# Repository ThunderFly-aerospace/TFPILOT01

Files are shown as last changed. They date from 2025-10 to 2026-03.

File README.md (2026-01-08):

# Teensy 4.1 - Based Flight-Controller for dRehmFlight

This project is a hardware controller board designed specifically for use with the [dRehmFlight open-source flight controller firmware](https://github.com/nickrehm/dRehmFlight). It is based on the Teensy 4.1 microcontroller and provides all the essential interfaces and components needed for a compact, capable flight control unit.

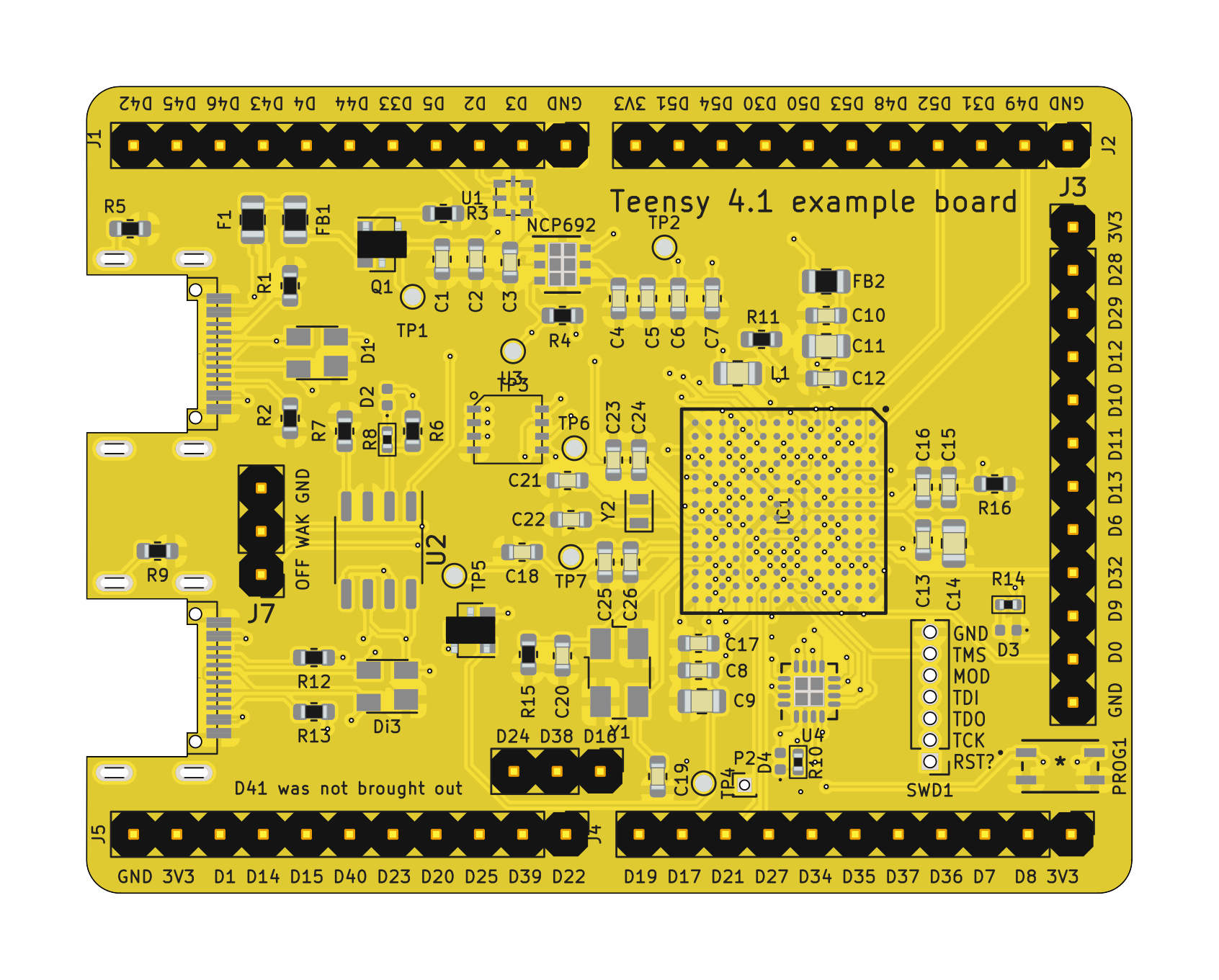
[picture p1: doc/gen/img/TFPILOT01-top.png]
TFPILOT01 top

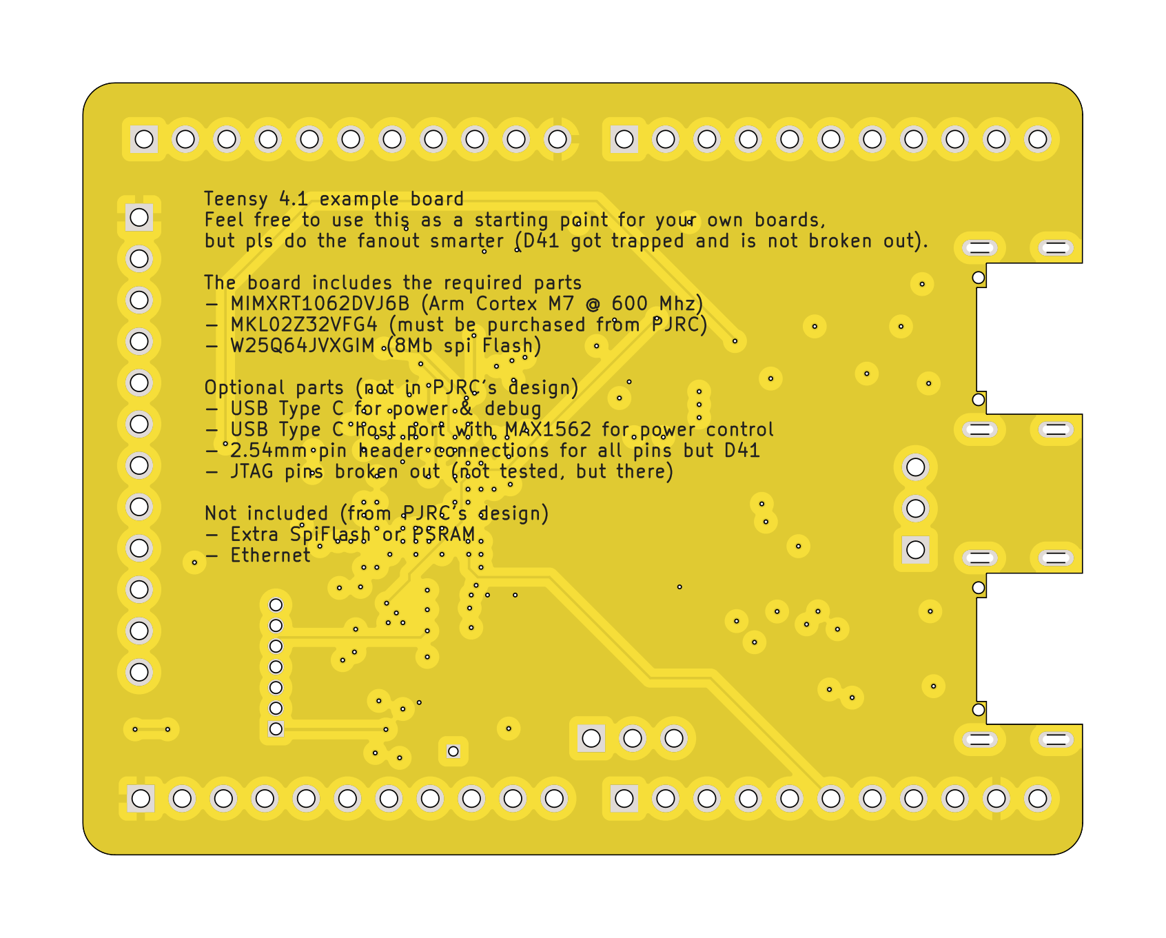
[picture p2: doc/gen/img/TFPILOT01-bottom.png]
TFPILOT01 bottom


## Features

### Core Components

* **Teensy 4.1** (MIMXRT1062DVJ6B – Arm Cortex-M7 @ 600 MHz)
* **MKL02Z32VFG4** bootloader MCU (required for Teensy compatibility)
* **W25Q64JVXGIM** 8 Mb SPI Flash memory

### Sensors

* **GY-91 (MPU9250 + BMP280)** IMU module connected via **SPI** for reduced latency.

  * Replaces the GY-521 module (MPU6050) commonly used in the default dRehmFlight configuration
  * Integrated magnetometer (AK8963) provides full 9‑DOF capability
  * Integrated BMP280 barometric sensor for altitude estimation

### Storage

* **microSD card slot** for onboard data logging

### Power and Connectivity

* **XT30 power connector** for powering both the autopilot and connected servos
* **PWM outputs** using standard RC servo connectors for direct model integration
* **Multiple high-current GPIO outputs** with transistor drivers for heating control, triggering pyrotechnic or other one-shot actuators
* **USB‑C connector** for power and debug interface (compatible with PJRC Teensy bootloader)

### Expansion and Debugging

* **2.54 mm pin header** for access to I/O pins (except D41)
* **JTAG pins** broken out (not yet tested)

## Acknowledgements

This updated board builds upon the original Teensy 4.1 KiCad example design, transforming it into a purpose-built flight controller platform optimized for dRehmFlight. It adds robust sensing, storage, power distribution, and actuator control features for experimental UAV and aerospace applications.

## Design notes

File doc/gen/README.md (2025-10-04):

# PCB

Board size: 61.5x47.5 mm (2.42x1.87 inches)

- This is the size of the rectangle that contains the board
- Thickness: 4.69 mm (185 mils)
- Material: FR4
- Finish: None
- Layers: 4
- Copper thickness: 35 µm

Solder mask: TOP / BOTTOM

- Color: Green

Silk screen: TOP / BOTTOM

- Color: White

Stackup:

| Name | Type | Color | Thickness [µm]| Material | Er | Loss tan |
|---|---|---|---|---|---|---|
| F.SilkS | Top Silk Screen | | | | | |
| F.Paste | Top Solder Paste | | | | | |
| F.Mask | Top Solder Mask | Green | 10 | | | |
| F.Cu | copper | | 35 | | | |
| dielectric 1 | core | | 1510 | FR4 | 4.5 | 0.020 |
| In1.Cu | copper | | 35 | | | |
| dielectric 2 | prepreg | | 1510 | FR4 | 4.5 | 0.020 |
| In2.Cu | copper | | 35 | | | |
| dielectric 3 | core | | 1510 | FR4 | 4.5 | 0.020 |
| B.Cu | copper | | 35 | | | |
| B.Mask | Bottom Solder Mask | Green | 10 | | | |
| B.Paste | Bottom Solder Paste  | | | | | |
| B.SilkS | Bottom Silk Screen | | | | | |

# Important sizes

Clearance: 0.1 mm (4 mils)

Track width: 0.15 mm (6 mils)

- By design rules: 0.15 mm (6 mils)

Drill: 0.25 mm (10 mils)

- Vias: 0.25 mm (10 mils) [Design: 0.25 mm (10 mils)]
- Pads: 0.6 mm (24 mils)
- The above values are real drill sizes, they add 0.1 mm (4 mils) to plated holes (PTH)

Via: 0.45/0.15 mm (18/6 mils)

- By design rules: 0.15/0.15 mm (6/6 mils)
- Micro via: yes [0.2/0.1 mm (8/4 mils)]
- Buried/blind via: yes
- Total: 145 (thru: 145 buried/blind: 0 micro: 0)

Outer Annular Ring: 0.1 mm (4 mils)

- By design rules: 0.13 mm (5 mils)

Eurocircuits class: 8E
- Using min drill 0.2 mm for an OAR of 0.13 mm

# General stats

Components count: (SMD/THT)

- Top: 62/11 (SMD + THT)
- Bottom: 0/0 (NONE)

Defined tracks:

- 0.16 mm (6 mils)
- 0.2 mm (8 mils)

Used tracks:

- 0.15 mm (6 mils) (68) defined: no
- 0.16 mm (6 mils) (744) defined: yes
- 0.2 mm (8 mils) (173) defined: yes
- 0.25 mm (10 mils) (30) defined: no

Defined vias:

- 0.5/0.15 mm (20/6 mils)

Used vias:

- 0.45/0.15 mm (18/6 mils) (Count: 145, Aspect: 10.4 C) defined: no

Holes (excluding vias):

- 0.5 mm (20 mils) (1)
- 0.65 mm (26 mils) (11)
- 1.0 mm (39 mils) (62)

Oval holes:

- 0.5x1.65 mm (20x65 mils) (8)

Drill tools (including vias and computing adjusts and rounding):

- 0.25 mm (10 mils) (145)
- 0.6 mm (24 mils) (9)
- 0.65 mm (26 mils) (4)
- 0.75 mm (30 mils) (7)
- 1.1 mm (43 mils) (62)

Solder paste stats:

Using a paste with 87.75 % alloy, that has an specific gravity for the alloy of 7.4 g/cm³
and 1.0 g/cm³ for the flux. This paste has an specific gravity of  4.15 g/cm³.

The stencil thickness is  0.12 mm.

| Side | Pads with paste | Area [mm²] | Paste [g] |
|---|---|---|---|
| Total  | 406 | 166.59 | 0.83 |

Note: this is just an approximation to the theoretical value. Margins of the solder mask and waste aren't computed.

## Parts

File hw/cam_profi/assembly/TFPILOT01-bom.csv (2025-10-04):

Component | Description | Part | References | Value | Footprint | Quantity Per PCB | Datasheet | mfgr | mpn | height | mouser part number | mouser price/stock | manufacturer_name | manufacturer_part_number
1 | Unpolarized capacitor | C | C21C22 | 9pf | C_0603_1608Metric | 2 | ~ | Jellybean (X7R or better) | GRM1885C1H9R0DA01D
2 | Unpolarized capacitor | C | C19C20 | 10pf | C_0603_1608Metric | 2 | ~ | Jellybean (X7R or better) | CC0603KRNPO9BN100
3 | Unpolarized capacitor | C | C5C16 | 10nf | C_0603_1608Metric | 2 | ~ | Jellybean (X7R or better) | 0603B103K160CT
4 | Unpolarized capacitor | C | C1C2C4C8C10C13C17C18C23C25 | 0.22uf | C_0603_1608Metric | 10 | ~ | Jellybean (X7R or better) | CC0603KRX7R6BB224
5 | Unpolarized capacitor | C | C3C7 | 2.2uf | C_0603_1608Metric | 2 | ~ | Jellybean (X7R or better) | CL10B225KP8NNNC
6 | Unpolarized capacitor | C | C6C12C15C24C26 | 4.7uf | C_0603_1608Metric | 5 | ~ | Jellybean (X7R or better) | CL10B475KQ8NQNC
7 | Unpolarized capacitor | C | C9C11C14 | 10uf | C_0805_2012Metric | 3 | ~ | Jellybean (X7R or better) | GRM21BR71A106KA73K
8 | dual schottky barrier diode, common cathode | BAT54C | D5 | BAT54C | SOT-23 | 1 | http://www.diodes.com/_files/datasheets/ds11005.pdf
9 | Light emitting diode | LED | D3D4 | LED | LED_0402_1005Metric | 2 | ~
10 | TVS Diode Array, 5.5V Standoff, 3 Channels, SOT-143 package | SP0503BAHT | D1 | SP0503BAHT | SOT-143 | 1 | http://www.littelfuse.com/~/media/files/littelfuse/technical%20resources/documents/data%20sheets/sp05xxba.pdf
11 | Fuse | Fuse | F1 | Fuse | R_0805_2012Metric | 1 | ~ | Bel Fuse Inc | 0ZCK0050FF2E
12 | Ferrite bead | Ferrite_Bead | FB1FB2 | Ferrite_Bead | R_0805_2012Metric | 2 | ~ | Taiyo Yuden | FBMH2012HM121-T‎
13 | IC MCU 32BIT EXT MEM 196MAPBGA | MIMXRT1062DVJ6B | IC1 | MIMXRT1062DVJ6B | BGA196C80P14X14_1200X1200X152 | 1 | https://www.nxp.com/docs/en/nxp/data-sheets/IMXRT1060CEC.pdf |  |  | 1.52 | 771-MIMXRT1062DVJ6B | https://www.mouser.co.uk/ProductDetail/NXP-Semiconductors/MIMXRT1062DVJ6B?qs=BJlw7L4Cy7%252B08A9rbTO5WQ%3D%3D | NXP | MIMXRT1062DVJ6B
14 | Generic connector, single row, 01x03, script generated (kicad-library-utils/schlib/autogen/connector/) | Conn_01x03_Male | J6J7 | Conn_01x03_Male | PinHeader_1x03_P2.54mm_Vertical | 2 | ~
15 | Inductor | L | L1 | 4.7uH | C_0805_2012Metric | 1 | ~ |  | LQM21PN4R7MGRD
16 | 3x3mm LDO, 1A | OnSemi NCP692, fixed version | NCP692 | OnSemi NCP692, fixed version | DFN-6-1EP_3x3mm_P0.95mm_EP1.7x2.6mm | 1 | https://www.onsemi.com/pdf/datasheet/ncp690-d.pdf | Onsemi | NCP692MN33T2G
17 | Push button switch, generic, two pins | SW_Push | PROG1 | SW_Push | KMR241GLFS | 1 |  | C&K | KMR241GLFS
18 | P-MOSFET transistor, gate/drain/source | Q_PMOS_GDS | Q1 | Q_PMOS_GDS_DMP3125L | SOT-23 | 1 | https://www.diodes.com/assets/Datasheets/DMP3125L.pdf
19 | Resistor | R | R10R14 | 1k | R_0402_1005Metric | 2 | ~
20 | Resistor | R | R1R2 | 5.1k | R_0603_1608Metric | 2 | ~ | Jellybean | RC0603FR-075K1L
21 | Resistor | R | R3R4R11 | 100k | R_0603_1608Metric | 3 | ~
22 | Resistor | R | R5 | 1M | R_0603_1608Metric | 1 | ~
23 | Resistor | R | R15 | 2.2M | R_0603_1608Metric | 1 | ~
24 | Generic connector, single row, 01x07, script generated (kicad-library-utils/schlib/autogen/connector/) | Conn_01x07_Female | SWD1 | SWD | PinHeader_1x07_P1.27mm_Vertical | 1 | ~
25 | Kinetis KL02 series, 48-MHz/32-bit ARM Cortex-M0+, 32 kB flash, 4 kB SRAM, QFN-16 | MKL02Z32VFG4 | U4 | MKL02Z32VFG4 | QFN-16-1EP_3x3mm_P0.5mm_EP1.8x1.8mm | 1 | http://www.nxp.com/docs/en/data-sheet/KL02P32M48SF0.pdf | Supplied by Roest Coffee | Custom firmware part
26 | Flash chip for T4.1 designs, XSON-8 package, W25Q64JVXGIM TR, NOR Flash spiFlash, 64M-bit, DTR, 4Kb Uniform Sector | W25Q64VXGIM | U3 | W25Q64JVXGIM | XSON8_4x4mm | 1 | https://www.winbond.com/resource-files/W25Q64JV%20RevK%2003102021%20Plus.pdf
27 |  | opto_APA102-2020 | U1 | opto_APA102-2020 | APA102-2020 | 1 | https://www.digikey.com/htmldatasheets/production/2046355/0/0/1/3587.pdf
28 | USB 2.0-only Type-C Receptacle connector | USB_C_Receptacle_USB2.0 | USB_UFP1 | USB_C_Receptacle_USB2.0 | TYPE-C-31-M-14 | 1 | https://www.usb.org/sites/default/files/documents/usb_type-c.zip
29 | Two pin crystal | Crystal | Y2 | Crystal | Crystal_SMD_2012-2Pin_2.0x1.2mm | 1 | ~ | Abracon | ABS06-32.768KHZ-9-1-T
30 | Four pin crystal, GND on pins 2 and 4 | Crystal_GND24 | Y1 | Crystal_GND23 | Crystal_SMD_Abracon_ABM3B-4Pin_5.0x3.2mm | 1 | ~

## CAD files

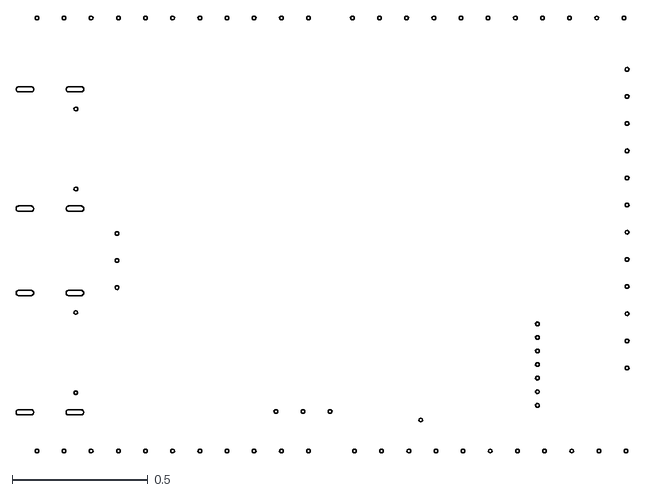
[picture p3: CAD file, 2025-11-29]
doc/gen/dxf/TFPILOT01-User_9.dxf
2.26 x 1.61

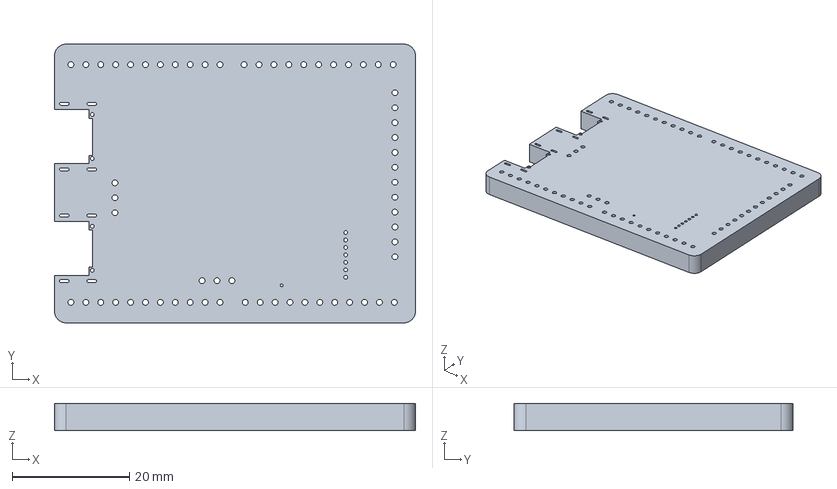
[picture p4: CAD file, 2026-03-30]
doc/gen/TFPILOT01.step
61.5 x 47.5 x 4.60 mm

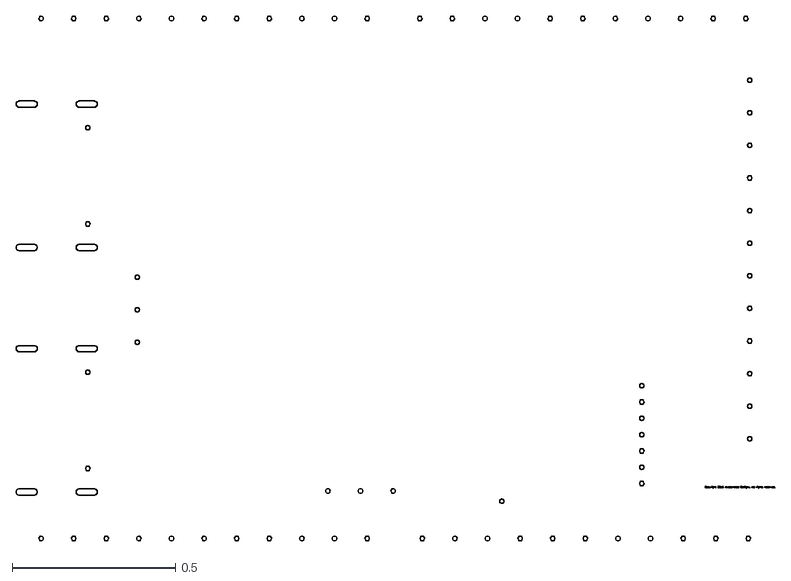
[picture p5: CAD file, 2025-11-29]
doc/gen/dxf/TFPILOT01-User_Comments.dxf
2.33 x 1.61

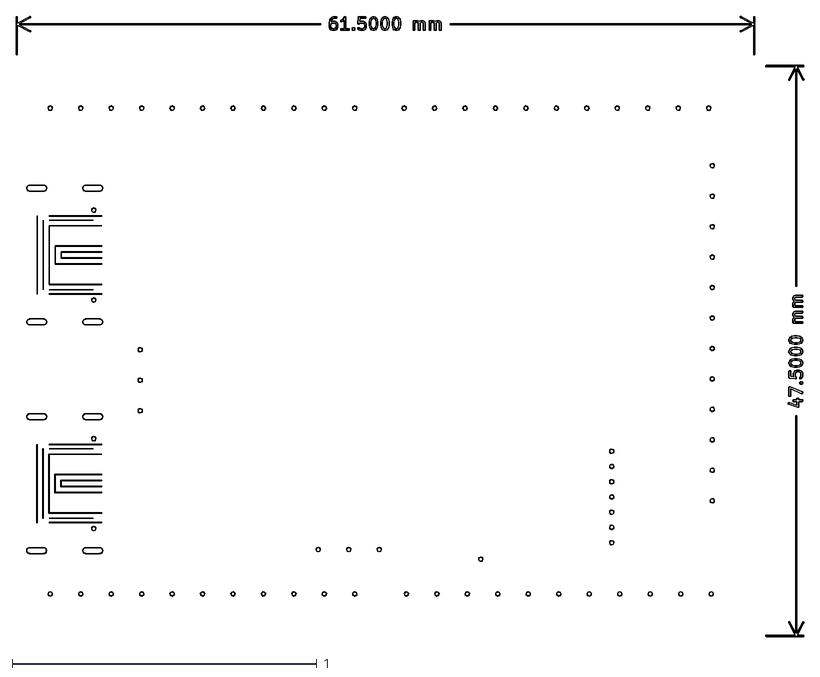
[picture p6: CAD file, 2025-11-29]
doc/gen/dxf/TFPILOT01-User_Drawings.dxf
2.59 x 2.03

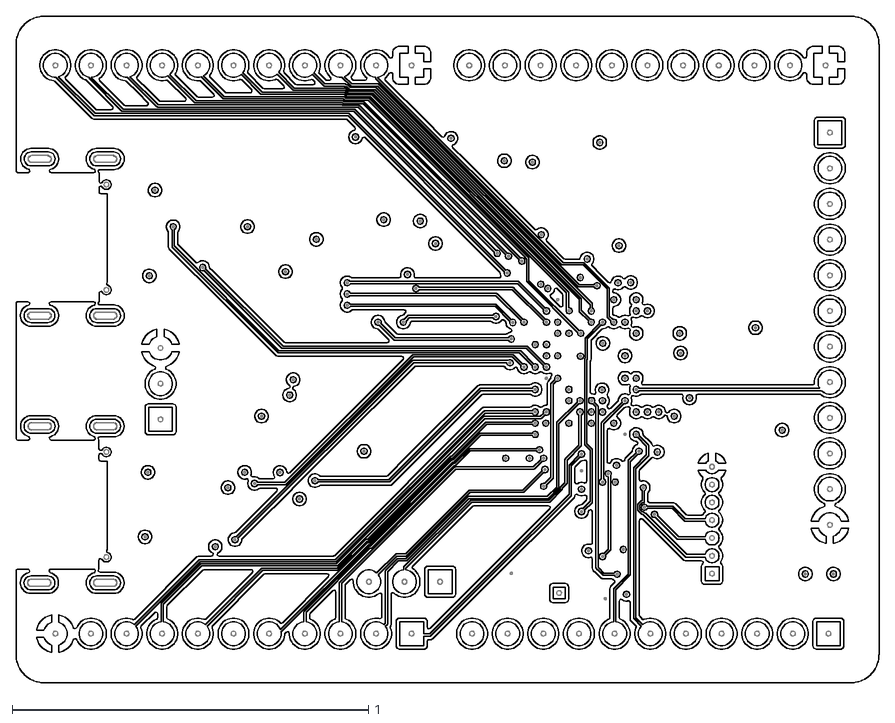
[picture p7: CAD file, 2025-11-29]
doc/gen/dxf/TFPILOT01-In2_Cu.dxf
2.42 x 1.87

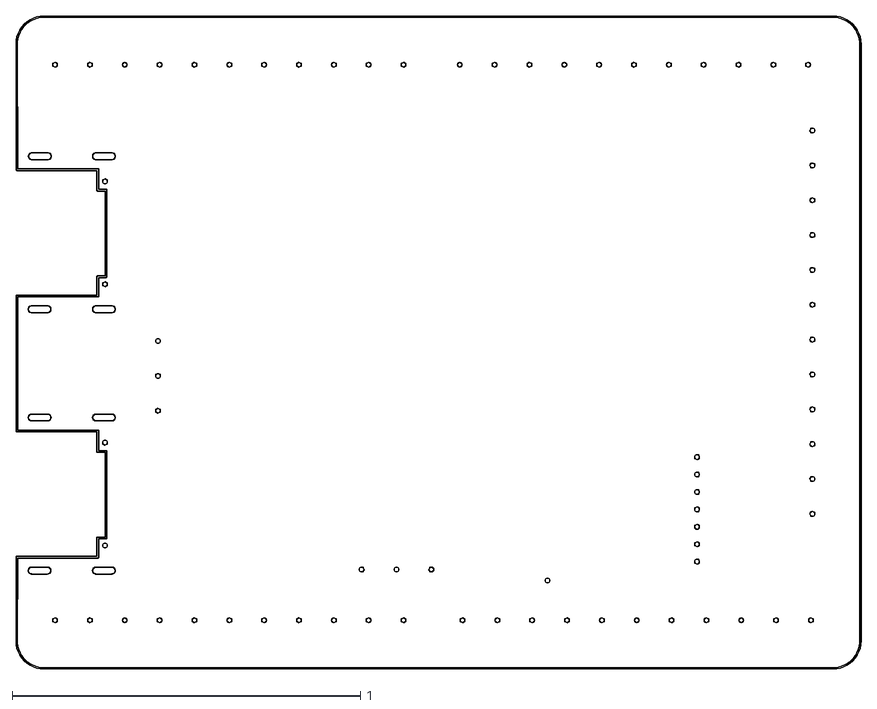
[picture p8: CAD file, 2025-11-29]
doc/gen/dxf/TFPILOT01-Edge_Cuts.dxf
2.43 x 1.87

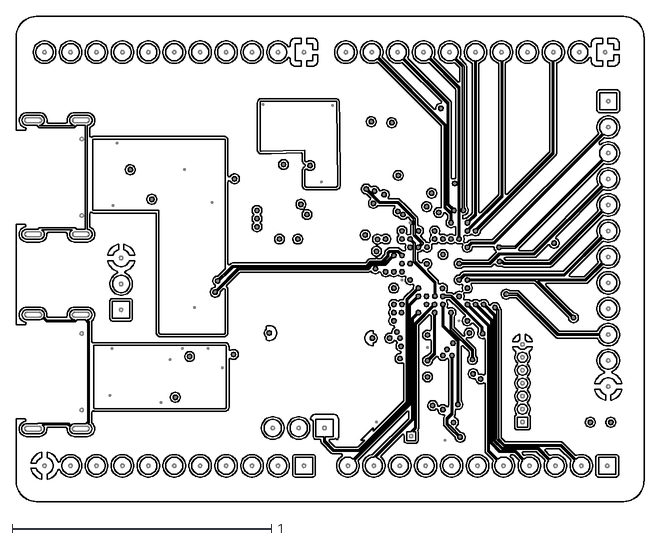
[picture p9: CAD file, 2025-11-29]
doc/gen/dxf/TFPILOT01-In1_Cu.dxf
2.42 x 1.87

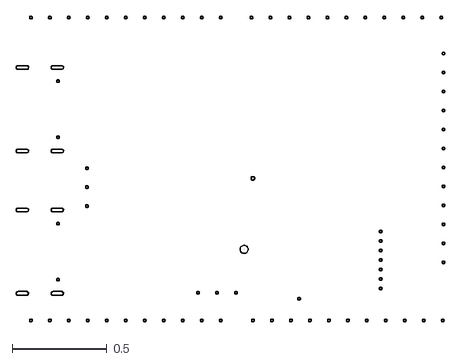
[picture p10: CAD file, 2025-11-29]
doc/gen/dxf/TFPILOT01-F_Adhesive.dxf
2.26 x 1.61

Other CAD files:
doc/gen/dxf/TFPILOT01-B_Adhesive.dxf
doc/gen/dxf/TFPILOT01-B_Cu.dxf
doc/gen/dxf/TFPILOT01-B_Mask.dxf
doc/gen/dxf/TFPILOT01-B_Paste.dxf
doc/gen/dxf/TFPILOT01-B_Silkscreen.dxf
doc/gen/dxf/TFPILOT01-F_Courtyard.dxf
doc/gen/dxf/TFPILOT01-F_Cu.dxf
doc/gen/dxf/TFPILOT01-F_Fab.dxf
doc/gen/dxf/TFPILOT01-F_Mask.dxf
doc/gen/dxf/TFPILOT01-F_Paste.dxf
doc/gen/dxf/TFPILOT01-F_Silkscreen.dxf

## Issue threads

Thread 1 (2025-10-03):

IMU integration

kaklik, 2025-10-03:
Lepší je použít GY-91 s MPU9250, který má i magnetometr. Je jej spíše vhodné připojit přes SPI, místo defaultního I2C v [dRehmFlight](https://github.com/nickrehm/dRehmFlight).

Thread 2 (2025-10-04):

Check existing design for defects

kaklik, 2025-10-04:
- [lots of important information there](https://www.pjrc.com/store/ic_mkl02_t4.html)
-

## Know bugs (from the original readme)
This version is tested and works, but the MAX1562 that I used for the USB switch has inverted polarity from what is expected. You can get around this by using the alternate part MAX1563, or something else. Only reason I went with this 4A chip is the parts shortage.

I just removed the chip and soldered bodge-wires to bypass it. This also works, but I guess it then lacks protection. I've tested with keyboard & mouse.

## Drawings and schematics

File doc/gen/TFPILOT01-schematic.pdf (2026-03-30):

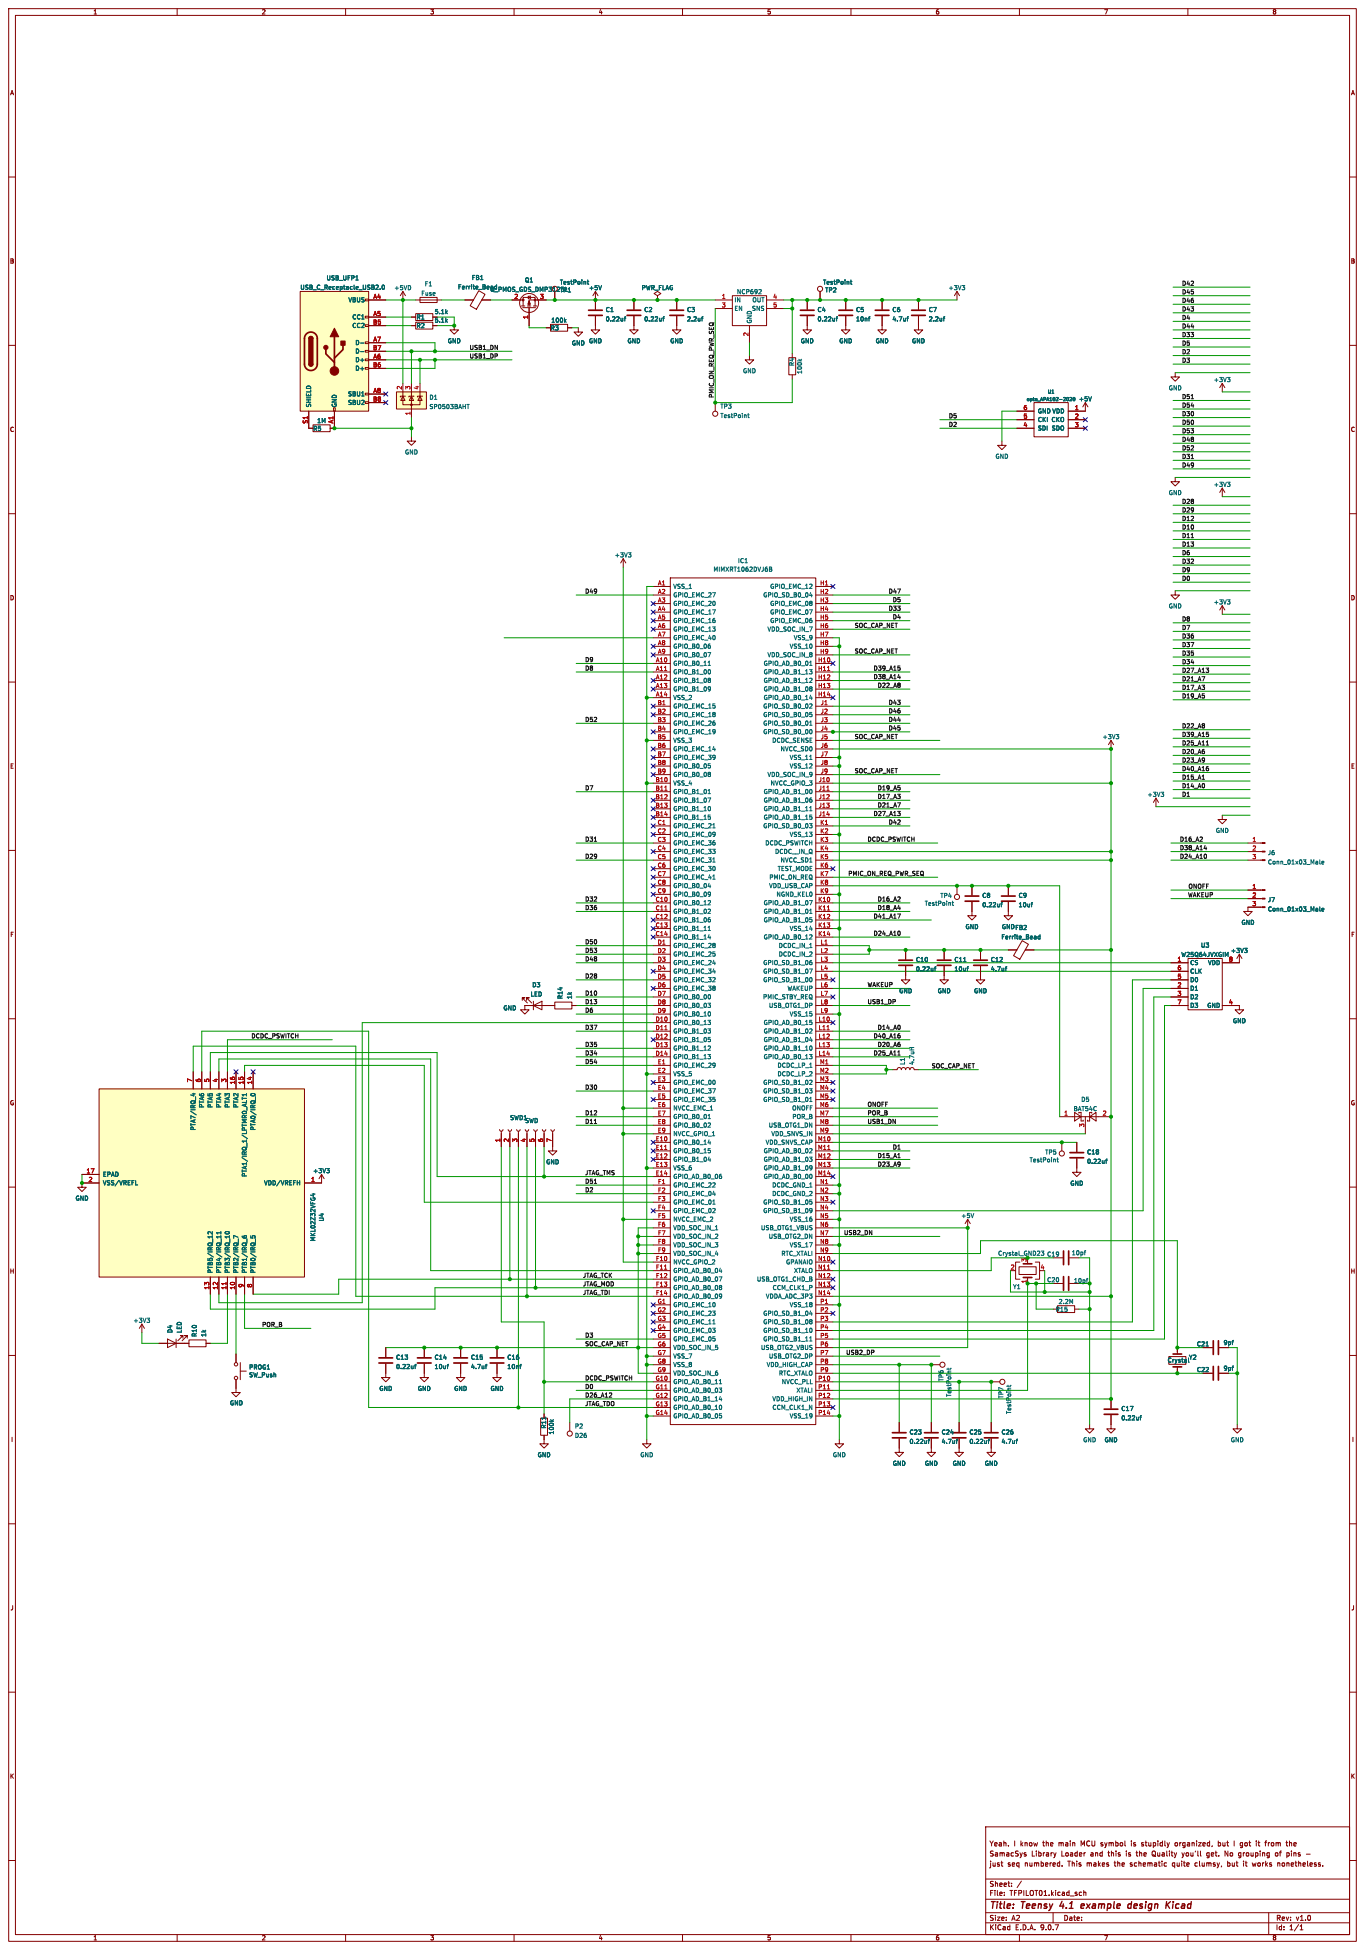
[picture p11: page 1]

2 OUT 4 SNS 5 NCP692 GND GND L14.7uH

7 EPAD 17 VDD/VREFH 1 VSS/VREFL 2 PTB0/IRQ_5

File: TFPILOT01.kicad_sch Sheet: /
Id: 1/1 Title: Teensy 4.1 example design Kicad

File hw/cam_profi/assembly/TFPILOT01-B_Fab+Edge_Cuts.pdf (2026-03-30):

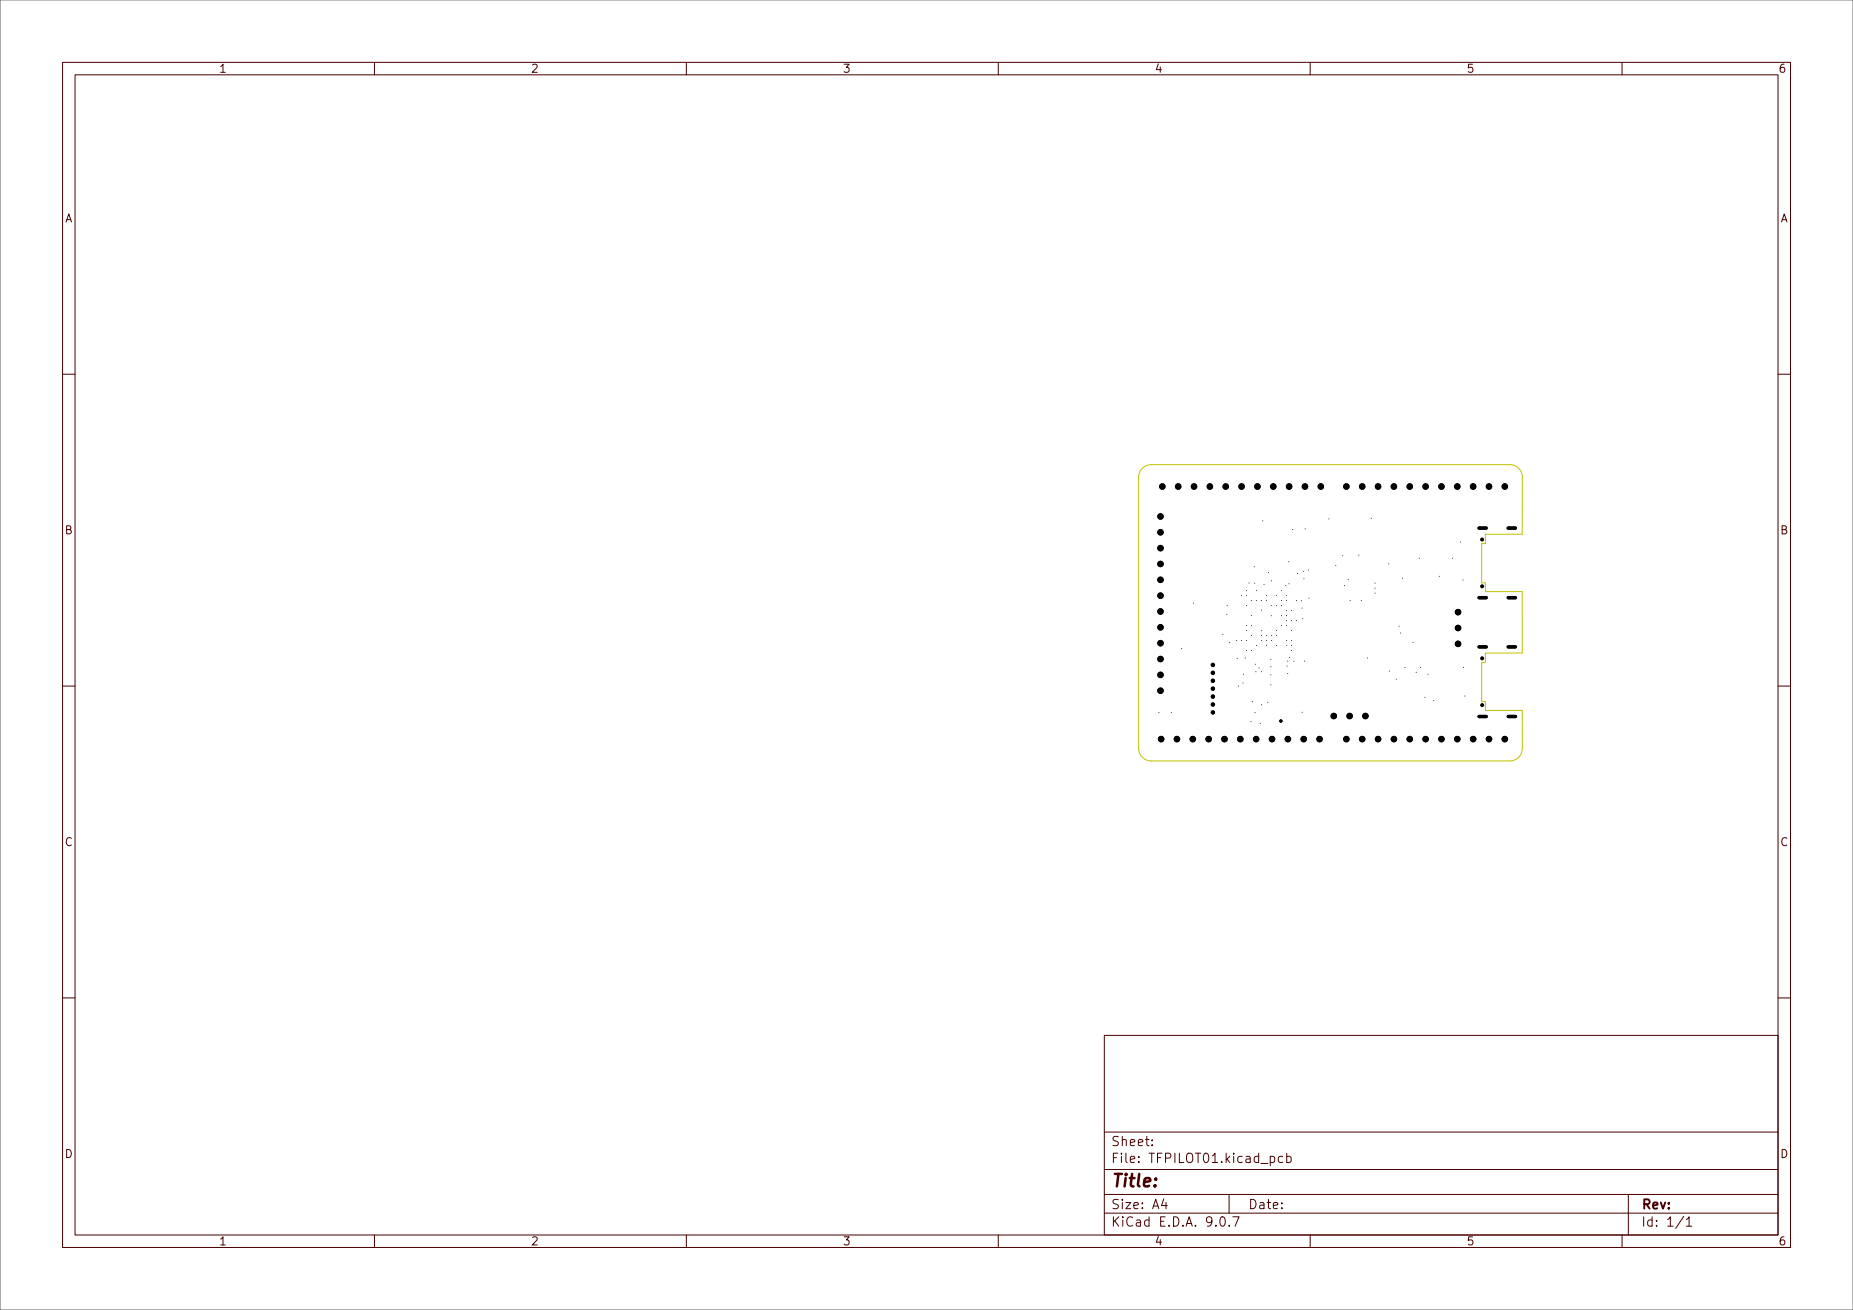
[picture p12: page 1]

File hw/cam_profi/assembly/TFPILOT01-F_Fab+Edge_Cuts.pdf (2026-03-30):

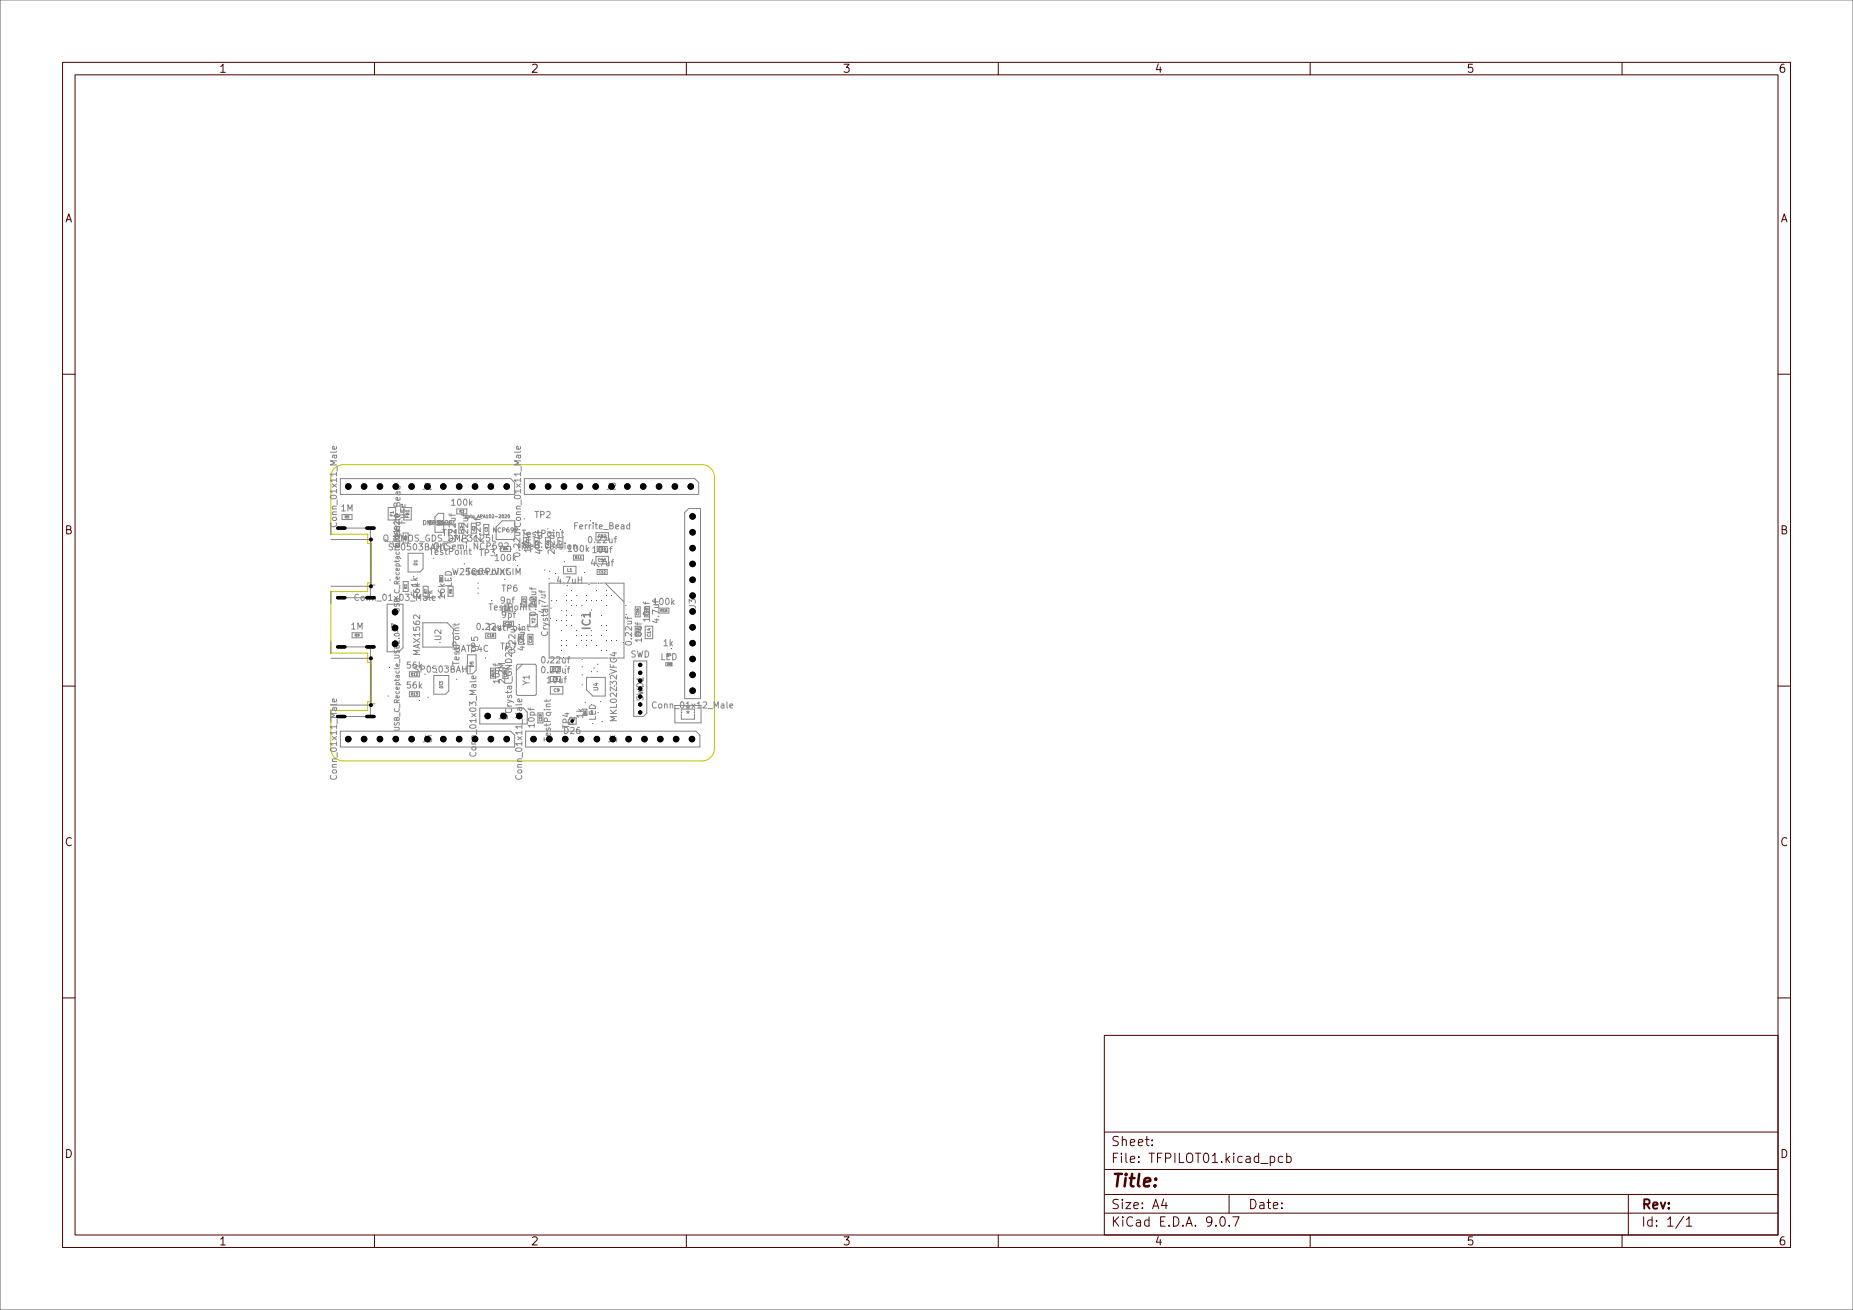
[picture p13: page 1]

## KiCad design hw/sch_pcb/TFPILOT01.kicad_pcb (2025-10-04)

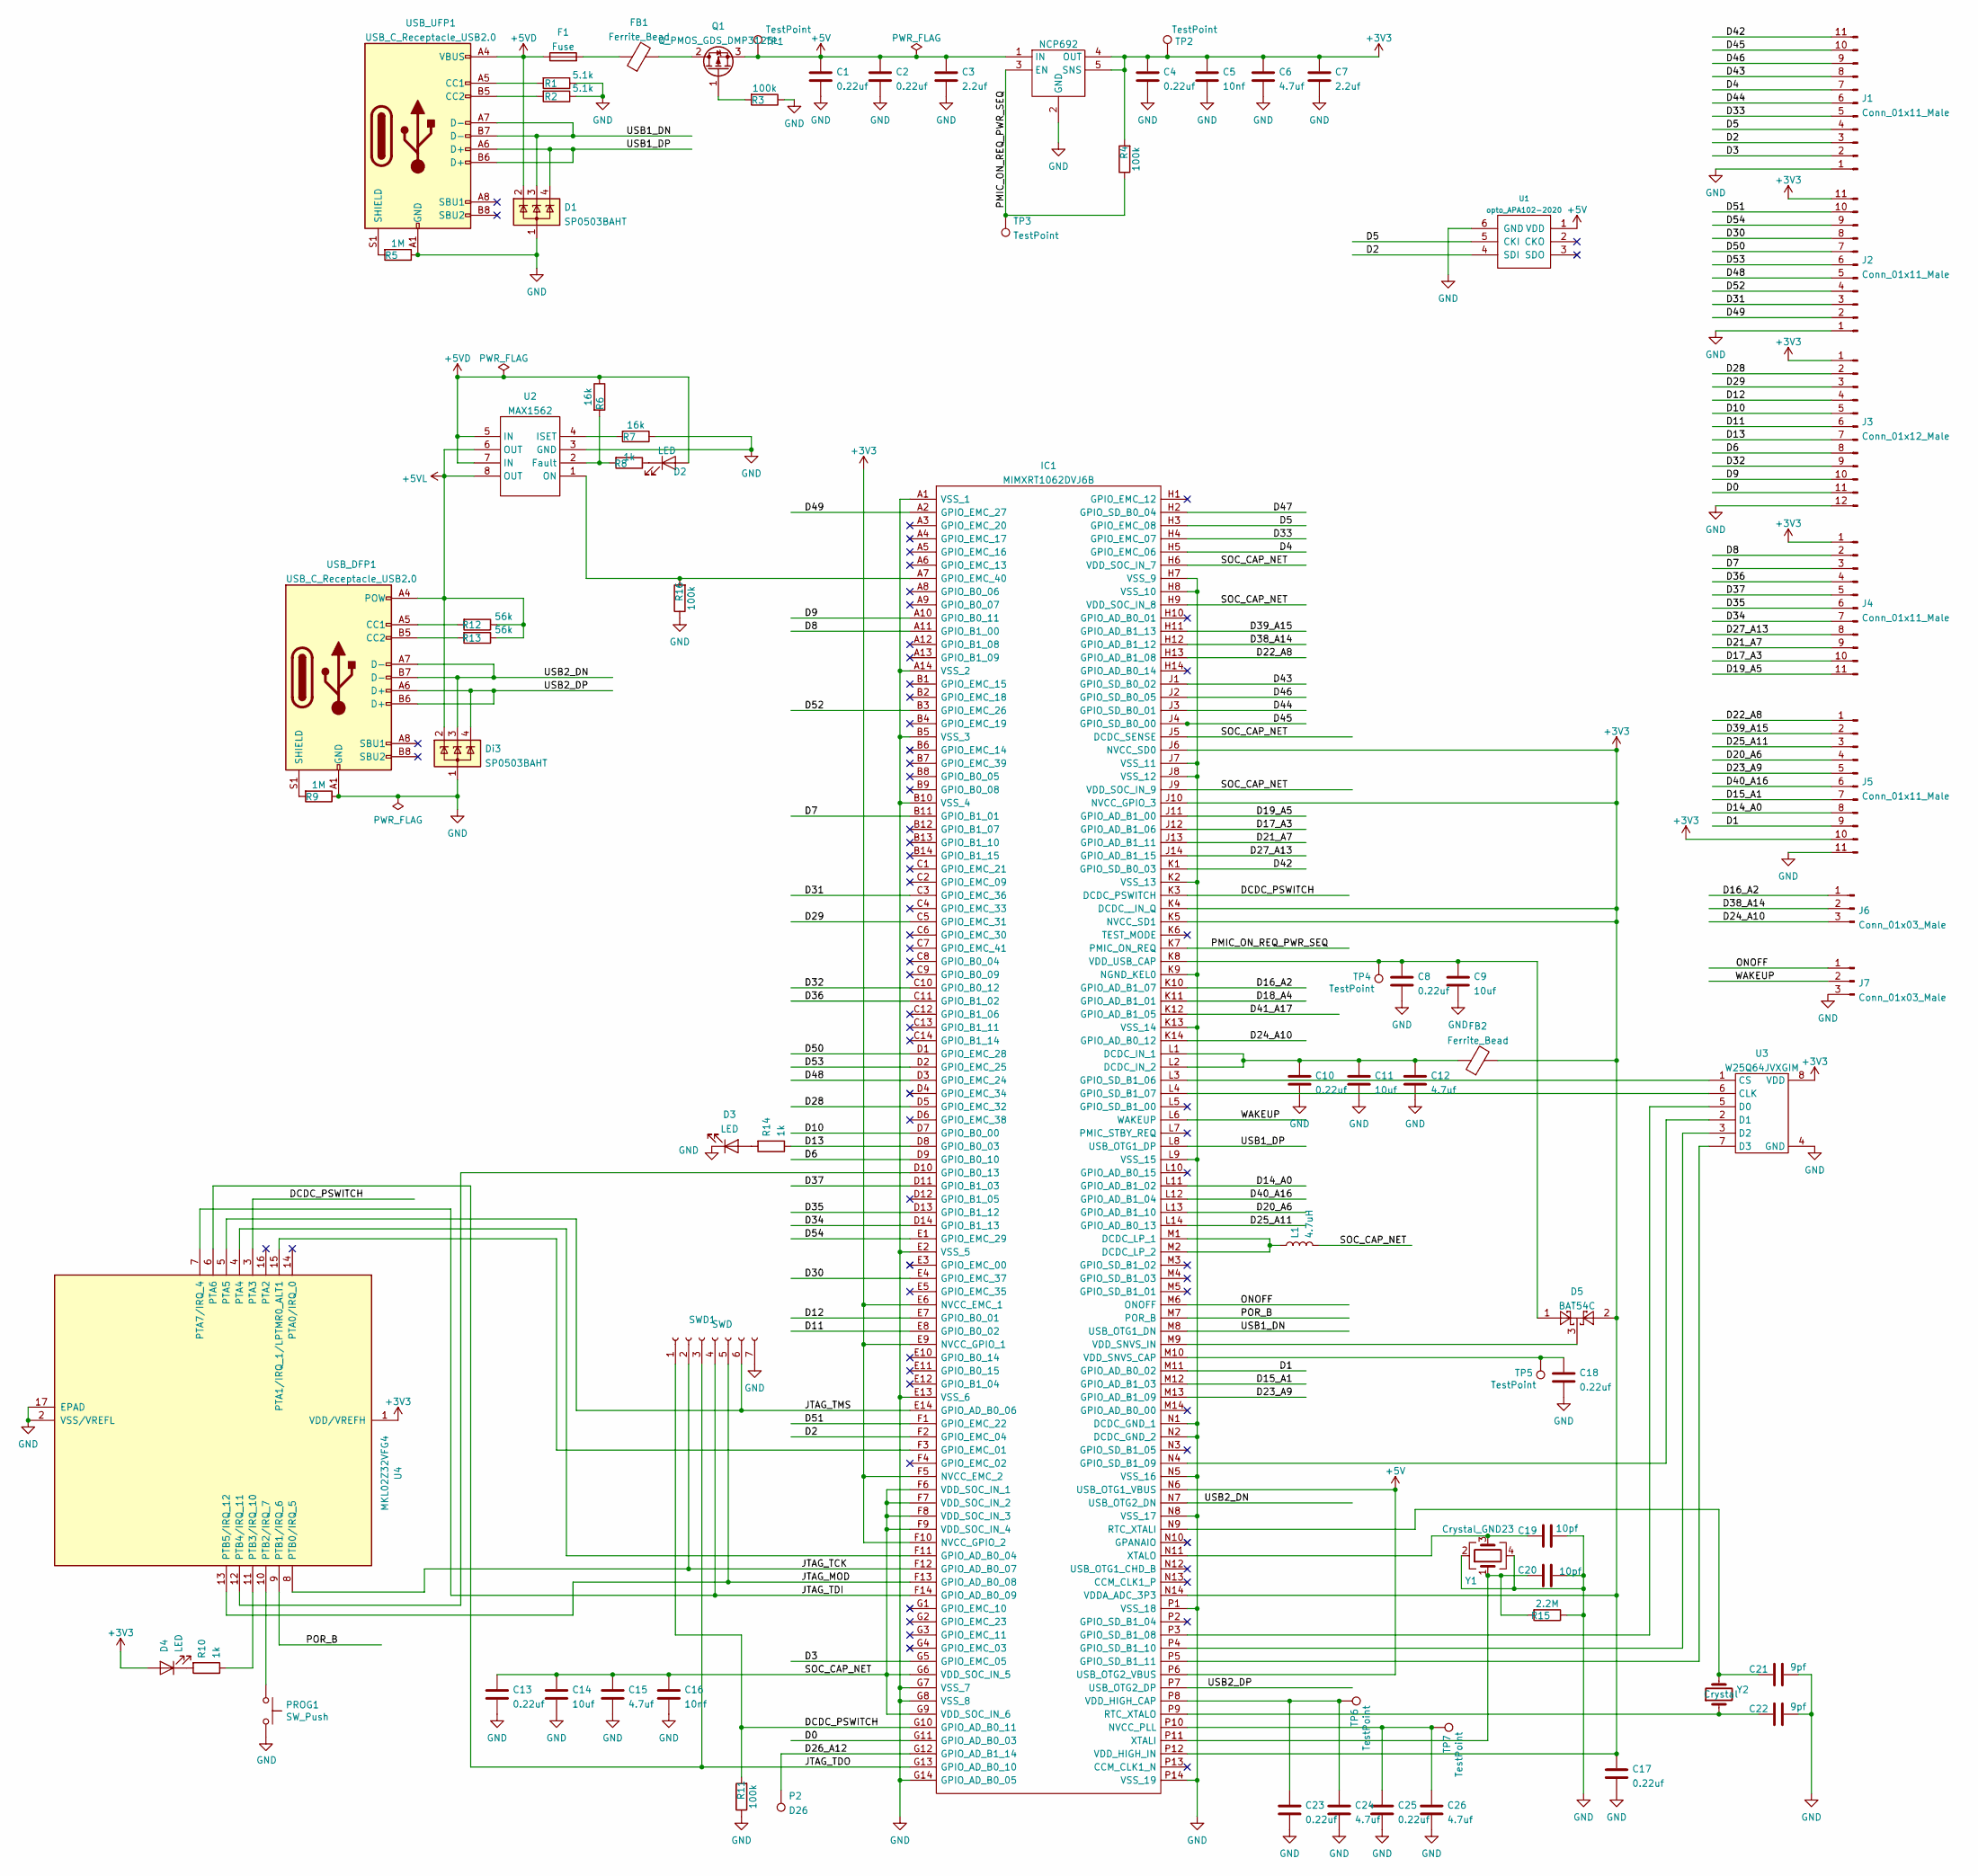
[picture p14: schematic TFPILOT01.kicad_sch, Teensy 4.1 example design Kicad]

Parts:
C1, C2, C4, C8, C10, C13, C17, C18, C23, C25: 0.22uf; C_0603_1608Metric; MPN CC0603KRX7R6BB224
C3, C7: 2.2uf; C_0603_1608Metric; MPN CL10B225KP8NNNC
C5, C16: 10nf; C_0603_1608Metric; MPN 0603B103K160CT
C6, C12, C15, C24, C26: 4.7uf; C_0603_1608Metric; MPN CL10B475KQ8NQNC
C9, C11, C14: 10uf; C_0805_2012Metric; MPN GRM21BR71A106KA73K
C19, C20: 10pf; C_0603_1608Metric; MPN CC0603KRNPO9BN100
C21, C22: 9pf; C_0603_1608Metric; MPN GRM1885C1H9R0DA01D
D1: SP0503BAHT; SOT-143
D2, D3, D4: LED; LED_0402_1005Metric
D5: BAT54C; SOT-23
Di3: SP0503BAHT; SOT-143
F1: Fuse; R_0805_2012Metric; MPN 0ZCK0050FF2E
FB1, FB2: Ferrite_Bead; R_0805_2012Metric; MPN FBMH2012HM121-T‎
IC1: MIMXRT1062DVJ6B; BGA196C80P14X14_1200X1200X152; Mouser Part Number 771-MIMXRT1062DVJ6B
J1, J2, J4, J5: Conn_01x11_Male; PinHeader_1x11_P2.54mm_Vertical
J3: Conn_01x12_Male; PinHeader_1x12_P2.54mm_Vertical
J6, J7: Conn_01x03_Male; PinHeader_1x03_P2.54mm_Vertical
L1: 4.7uH; C_0805_2012Metric; MPN LQM21PN4R7MGRD
NCP692: OnSemi NCP692, fixed version; DFN-6-1EP_3x3mm_P0.95mm_EP1.7x2.6mm; MPN NCP692MN33T2G
P2: D26; PinHeader_1x01_P1.00mm_Vertical
PROG1: SW_Push; KMR241GLFS; MPN KMR241GLFS
Q1: Q_PMOS_GDS_DMP3125L; SOT-23
R1, R2: 5.1k; R_0603_1608Metric; MPN RC0603FR-075K1L
R3, R4, R11, R16: 100k; R_0603_1608Metric
R5, R9: 1M; R_0603_1608Metric
R6, R7: 16k; R_0603_1608Metric
R8, R10, R14: 1k; R_0402_1005Metric
R12, R13: 56k; R_0603_1608Metric; MPN RMCF0603FT56K0
R15: 2.2M; R_0603_1608Metric
SWD1: SWD; PinHeader_1x07_P1.27mm_Vertical
TP1, TP2, TP3, TP4, TP5, TP6, TP7: TestPoint; TestPoint_Pad_D1.0mm
U1: opto_APA102-2020; APA102-2020
U2: MAX1562; SO-8_3.9x4.9mm_P1.27mm
U3: W25Q64JVXGIM; XSON8_4x4mm
U4: MKL02Z32VFG4; QFN-16-1EP_3x3mm_P0.5mm_EP1.8x1.8mm; MPN Custom firmware part
USB_DFP1: USB_C_Receptacle_USB2.0; TYPE-C-31-M-14
USB_UFP1: USB_C_Receptacle_USB2.0; TYPE-C-31-M-14
Y1: Crystal_GND23; Crystal_SMD_Abracon_ABM3B-4Pin_5.0x3.2mm
Y2: Crystal; Crystal_SMD_2012-2Pin_2.0x1.2mm; MPN ABS06-32.768KHZ-9-1-T

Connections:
+3V3: C4.1, C5.1, C6.1, C7.1, C17.1, D4.2 (A), D5.2, FB2.2, IC1.E6 (NVCC_EMC_1), IC1.E9 (NVCC_GPIO_1), IC1.F5 (NVCC_EMC_2), IC1.F10 (NVCC_GPIO_2), IC1.J6 (NVCC_SD0), IC1.J10 (NVCC_GPIO_3), IC1.K4 (DCDC__IN_Q), IC1.K5 (NVCC_SD1), IC1.N14 (VDDA_ADC_3P3), IC1.P12 (VDD_HIGH_IN), J2.11, J3.1, J4.1, J5.10, NCP692.4 (OUT), NCP692.5 (SNS), R4.2, TP2.1, U3.8 (VDD), U4.1 (VDD/VREFH)
+5V: C1.1, C2.1, C3.1, IC1.N6 (USB_OTG1_VBUS), IC1.P6 (USB_OTG2_VBUS), NCP692.1 (IN), NCP692.6 (IN), Q1.3 (S), TP1.1, U1.1 (VDD)
+5VD: D1.2 (K), D2.2 (A), F1.1, R6.1, U2.5 (IN), U2.7 (IN), USB_UFP1.A4 (VBUS), USB_UFP1.A9 (VBUS), USB_UFP1.B4 (VBUS), USB_UFP1.B9 (VBUS)
+5VL: Di3.2 (K), R12.1, R13.1, U2.6 (OUT), U2.8 (OUT), USB_DFP1.A4 (POW), USB_DFP1.A9 (POW), USB_DFP1.B4 (POW), USB_DFP1.B9 (POW)
/D0: IC1.G11 (GPIO_AD_B0_03), J3.11
/D1: IC1.M11 (GPIO_AD_B0_02), J5.9
/D2: IC1.F2 (GPIO_EMC_04), J1.3, U1.4 (SDI)
/D3: IC1.G5 (GPIO_EMC_05), J1.2
/D4: IC1.H5 (GPIO_EMC_06), J1.7
/D5: IC1.H3 (GPIO_EMC_08), J1.4, U1.5 (CKI)
/D6: IC1.D9 (GPIO_B0_10), J3.8
/D7: IC1.B11 (GPIO_B1_01), J4.3
/D8: IC1.A11 (GPIO_B1_00), J4.2
/D9: IC1.A10 (GPIO_B0_11), J3.10
/D10: IC1.D7 (GPIO_B0_00), J3.5
/D11: IC1.E8 (GPIO_B0_02), J3.6
/D12: IC1.E7 (GPIO_B0_01), J3.4
/D13: IC1.D8 (GPIO_B0_03), J3.7, R14.1
/D14_A0: IC1.L11 (GPIO_AD_B1_02), J5.8
/D15_A1: IC1.M12 (GPIO_AD_B1_03), J5.7
/D16_A2: IC1.K10 (GPIO_AD_B1_07), J6.1
/D17_A3: IC1.J12 (GPIO_AD_B1_06), J4.10
/D18_A4: IC1.K11 (GPIO_AD_B1_01)
/D19_A5: IC1.J11 (GPIO_AD_B1_00), J4.11
/D20_A6: IC1.L13 (GPIO_AD_B1_10), J5.4
/D21_A7: IC1.J13 (GPIO_AD_B1_11), J4.9
/D22_A8: IC1.H13 (GPIO_AD_B1_08), J5.1
/D23_A9: IC1.M13 (GPIO_AD_B1_09), J5.5
/D24_A10: IC1.K14 (GPIO_AD_B0_12), J6.3
/D25_A11: IC1.L14 (GPIO_AD_B0_13), J5.3
/D26_A12: IC1.G12 (GPIO_AD_B1_14), P2.1
/D27_A13: IC1.J14 (GPIO_AD_B1_15), J4.8
/D28: IC1.D5 (GPIO_EMC_32), J3.2
/D29: IC1.C5 (GPIO_EMC_31), J3.3
/D30: IC1.E4 (GPIO_EMC_37), J2.8
/D31: IC1.C3 (GPIO_EMC_36), J2.3
/D32: IC1.C10 (GPIO_B0_12), J3.9
/D33: IC1.H4 (GPIO_EMC_07), J1.5
/D34: IC1.D14 (GPIO_B1_13), J4.7
/D35: IC1.D13 (GPIO_B1_12), J4.6
/D36: IC1.C11 (GPIO_B1_02), J4.4
/D37: IC1.D11 (GPIO_B1_03), J4.5
/D38_A14: IC1.H12 (GPIO_AD_B1_12), J6.2
/D39_A15: IC1.H11 (GPIO_AD_B1_13), J5.2
/D40_A16: IC1.L12 (GPIO_AD_B1_04), J5.6
/D41_A17: IC1.K12 (GPIO_AD_B1_05)
/D42: IC1.K1 (GPIO_SD_B0_03), J1.11
/D43: IC1.J1 (GPIO_SD_B0_02), J1.8
/D44: IC1.J3 (GPIO_SD_B0_01), J1.6
/D45: IC1.J4 (GPIO_SD_B0_00), J1.10
/D46: IC1.J2 (GPIO_SD_B0_05), J1.9
/D47: IC1.H2 (GPIO_SD_B0_04)
/D48: IC1.D3 (GPIO_EMC_24), J2.5
/D49: IC1.A2 (GPIO_EMC_27), J2.2
/D50: IC1.D1 (GPIO_EMC_28), J2.7
/D51: IC1.F1 (GPIO_EMC_22), J2.10
/D52: IC1.B3 (GPIO_EMC_26), J2.4
/D53: IC1.D2 (GPIO_EMC_25), J2.6
/D54: IC1.E1 (GPIO_EMC_29), J2.9
/DCDC_PSWITCH: IC1.G10 (GPIO_AD_B0_11), IC1.K3 (DCDC_PSWITCH), R11.2, SWD1.1, U4.3 (PTA3)
/JTAG_MOD: IC1.F13 (GPIO_AD_B0_08), SWD1.5, U4.13 (PTB5/IRQ_12)
/JTAG_TCK: IC1.F12 (GPIO_AD_B0_07), SWD1.2, U4.8 (PTB0/IRQ_5)
/JTAG_TDI: IC1.F14 (GPIO_AD_B0_09), SWD1.4, U4.7 (PTA7/IRQ_4)
/JTAG_TDO: IC1.G13 (GPIO_AD_B0_10), SWD1.3, U4.6 (PTA6)
/JTAG_TMS: IC1.E14 (GPIO_AD_B0_06), SWD1.6, U4.5 (PTA5)
/ONOFF: IC1.M6 (ONOFF), J7.1
/PMIC_ON_REQ_PWR_SEQ: IC1.K7 (PMIC_ON_REQ), NCP692.3 (EN), R4.1, TP3.1
/POR_B: IC1.M7 (POR_B), U4.9 (PTB1/IRQ_6)
/SOC_CAP_NET: C13.1, C14.1, C15.1, C16.1, IC1.F6 (VDD_SOC_IN_1), IC1.F7 (VDD_SOC_IN_2), IC1.F8 (VDD_SOC_IN_3), IC1.F9 (VDD_SOC_IN_4), IC1.G6 (VDD_SOC_IN_5), IC1.G9 (VDD_SOC_IN_6), IC1.H6 (VDD_SOC_IN_7), IC1.H9 (VDD_SOC_IN_8), IC1.J5 (DCDC_SENSE), IC1.J9 (VDD_SOC_IN_9), L1.2
/USB1_DN: D1.3 (K), IC1.M8 (USB_OTG1_DN), USB_UFP1.A7 (D-), USB_UFP1.B7 (D-)
/USB1_DP: D1.4 (K), IC1.L8 (USB_OTG1_DP), USB_UFP1.A6 (D+), USB_UFP1.B6 (D+)
/USB2_DN: Di3.3 (K), IC1.N7 (USB_OTG2_DN), USB_DFP1.A7 (D-), USB_DFP1.B7 (D-)
/USB2_DP: Di3.4 (K), IC1.P7 (USB_OTG2_DP), USB_DFP1.A6 (D+), USB_DFP1.B6 (D+)
/WAKEUP: IC1.L6 (WAKEUP), J7.2
GND: C1.2, C2.2, C3.2, C4.2, C5.2, C6.2, C7.2, C8.2, C9.2, C10.2, C11.2, C12.2, C13.2, C14.2, C15.2, C16.2, C17.2, C18.2, C19.2, C20.2, C21.2, C22.2, C23.2, C24.2, C25.2, C26.2, D1.1 (A), D3.1 (K), Di3.1 (A), IC1.A1 (VSS_1), IC1.A14 (VSS_2), IC1.B5 (VSS_3), IC1.B10 (VSS_4), IC1.E2 (VSS_5), IC1.E13 (VSS_6), IC1.G7 (VSS_7), IC1.G8 (VSS_8), IC1.G14 (GPIO_AD_B0_05), IC1.H7 (VSS_9), IC1.H8 (VSS_10), IC1.J7 (VSS_11), IC1.J8 (VSS_12), IC1.K2 (VSS_13), IC1.K9 (NGND_KEL0), IC1.K13 (VSS_14), IC1.L9 (VSS_15), IC1.N1 (DCDC_GND_1), IC1.N2 (DCDC_GND_2), IC1.N5 (VSS_16), IC1.N8 (VSS_17), IC1.P1 (VSS_18), IC1.P14 (VSS_19), J1.1, J2.1, J3.12, J5.11, J7.3, NCP692.2 (GND), NCP692.7 (GND), PROG1.2, R1.1, R2.1, R3.1, R5.1, R7.1, R9.1, R11.1, R15.1, R16.1, SWD1.7, U1.6 (GND), U2.3 (GND), U3.4 (GND), U4.2 (VSS/VREFL), U4.17 (EPAD), USB_DFP1.A1 (GND), USB_DFP1.A12 (GND), USB_DFP1.B1 (GND), USB_DFP1.B12 (GND), USB_UFP1.A1 (GND), USB_UFP1.A12 (GND), USB_UFP1.B1 (GND), USB_UFP1.B12 (GND), Y1.2, Y1.4
unnamed: D2.1 (K), R8.1
unnamed: D3.2 (A), R14.2
unnamed: D4.1 (K), R10.2
unnamed: F1.2, FB1.1
unnamed: C10.1, C11.1, C12.1, FB2.1, IC1.L1 (DCDC_IN_1), IC1.L2 (DCDC_IN_2)
unnamed: IC1.M1 (DCDC_LP_1), IC1.M2 (DCDC_LP_2), L1.1
unnamed: IC1.F11 (GPIO_AD_B0_04), U4.4 (PTA4)
unnamed: IC1.D10 (GPIO_B0_13), U4.12 (PTB4/IRQ_11)
unnamed: IC1.F3 (GPIO_EMC_01), U4.15 (PTA1/IRQ_1/LPTMR0_ALT1)
unnamed: IC1.A7 (GPIO_EMC_40), R16.2, U2.1 (ON)
unnamed: IC1.L3 (GPIO_SD_B1_06), U3.1 (CS)
unnamed: IC1.L4 (GPIO_SD_B1_07), U3.6 (CLK)
unnamed: IC1.P3 (GPIO_SD_B1_08), U3.5 (D0)
unnamed: IC1.N4 (GPIO_SD_B1_09), U3.2 (D1)
unnamed: IC1.P4 (GPIO_SD_B1_10), U3.3 (D2)
unnamed: IC1.P5 (GPIO_SD_B1_11), U3.7 (D3)
unnamed: C25.1, C26.1, IC1.P10 (NVCC_PLL), TP7.1
unnamed: C21.1, IC1.N9 (RTC_XTALI), Y2.2
unnamed: C22.1, IC1.P9 (RTC_XTALO), Y2.1
unnamed: C23.1, C24.1, IC1.P8 (VDD_HIGH_CAP), TP6.1
unnamed: C18.1, IC1.M10 (VDD_SNVS_CAP), TP5.1
unnamed: D5.3, IC1.M9 (VDD_SNVS_IN)
unnamed: C8.1, C9.1, D5.1, IC1.K8 (VDD_USB_CAP), TP4.1
unnamed: C20.1, IC1.P11 (XTALI), R15.2, Y1.1
unnamed: C19.1, IC1.N11 (XTALO), Y1.3
unnamed: FB1.2, Q1.2 (D)
unnamed: Q1.1 (G), R3.2
unnamed: R6.2, R8.2, U2.2 (Fault)
unnamed: R7.2, U2.4 (ISET)
unnamed: PROG1.1, U4.10 (PTB2/IRQ_7)
unnamed: R10.1, U4.11 (PTB3/IRQ_10)
unnamed: R12.2, USB_DFP1.A5 (CC1)
unnamed: R13.2, USB_DFP1.B5 (CC2)
unnamed: R9.2, USB_DFP1.S1 (SHIELD)
unnamed: R1.2, USB_UFP1.A5 (CC1)
unnamed: R2.2, USB_UFP1.B5 (CC2)
unnamed: R5.2, USB_UFP1.S1 (SHIELD)

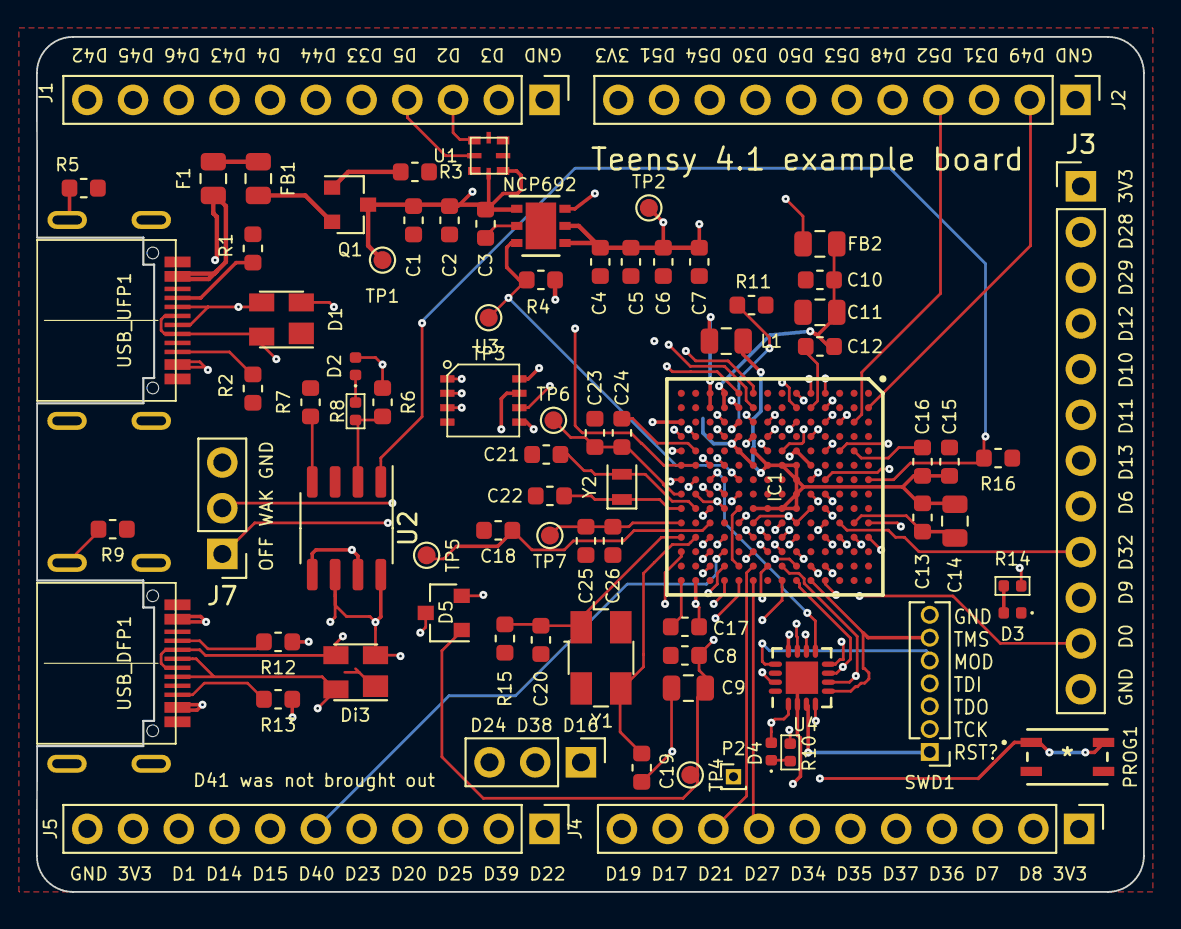
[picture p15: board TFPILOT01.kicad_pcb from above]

Board: 4 copper layers, 61.5 x 47.5 mm, 80 parts (0 on the bottom side), 109 nets.

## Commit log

2025-10-04 Modify repository structure. Cleanup Update project to KiCADv9. Activate workflows.
    [Teensy4.1-example.csv, Teensy4.1-example.kicad_pcb, Teensy4.1-example.kicad_sch]
2025-10-04 Add recovered KiCAD 9 project.
    [TFPILOT01.kicad_pcb, TFPILOT01.kicad_sch]
2025-10-04 Update actions products
    [TFPILOT01-B_Adhesive.dxf, TFPILOT01-B_Courtyard.dxf, TFPILOT01-B_Cu.dxf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]
2025-10-04 Remove USB-C host connector.
    [TFPILOT01.kicad_sch]
2026-02-15 Automatic update of KiCAD outputs
    [TFPILOT01.step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]

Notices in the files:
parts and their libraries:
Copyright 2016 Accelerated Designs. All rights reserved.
